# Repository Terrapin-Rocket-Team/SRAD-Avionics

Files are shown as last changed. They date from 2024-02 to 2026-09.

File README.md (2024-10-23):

# SRAD_Avionics
Code and PCBs for the avionics subteam for the SRAD flight computer and side projects.

The avionics subteam manages this repo, as well as the `Multi-Mission-Flight-Software` and `Ground Station`
repositories. Look at the *Issues* tab for tasks that need to be done, and the *Projects* tab for the current
status of the Avionics subteam as a whole. 

Most of our development for our competition rocket systems will be within the `/Spaceport/` directory. Here, the parts 
are broken up by whether they are hardware, PCBs, or code. 

If writing software for the main embedded system, open the [`Teensy-Based-Avionics`](./Spaceport/Code/Teensy-Based-Avionics) 
folder using [Platformio](https://platformio.org/) in VSCode, and make your edits there. For hardware, the files for a single 
board come in sets of 3, with the extensions `.kicad_pro`, `.kicad_pcb`, and `.kicad_sch`. Editing these files affects the 
PCB's layup.

## Setup
Visit the Software Training and Electronics Training modules for more information on how to start learning 
and getting started.

For installation, the `Ground Station` repository is submoduled on this repository. Submodules are not cloned by git by default. 

To clone the submodule when cloning the repo run:
```
git clone --recurse-submodules [url]
```
To clone the submodule within an existing clone of the repo run:
```
git submodule init
git submodule update
```

To get the latest changes for the submodule run:
```
git pull
git submodule update
```

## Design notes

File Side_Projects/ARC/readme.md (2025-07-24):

# Avionics Rotating Camera (ARC)

A live video system able to transmit medium quality 1280x720 30fps video based around the Raspberry Pi 5. It uses AV1 encoding for live video transmission. If you have any questions or would like to contribute, please contact Joseph Hauerstein on Slack or at jhauerst@terpmail.umd.edu.

***This project is still in the early stages of development, so the information here could be imcomplete or inaccurate***

## Setup

Clone the git repository or copy this folder onto a Raspberry Pi, then navigate to this directory in a command window and run the setup script.

```bash 
chmod +x setup.sh && sudo ./setup.sh
```

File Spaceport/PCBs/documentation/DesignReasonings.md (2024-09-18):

## Intro

### All files are located on the `new-pcbs` branch under `Spaceport\24-25\PCBs`.

After the meeting in early July, I wanted to play around designing PCBs because I thought it would be pretty neat. Before this exercise, I knew absolutely nothing about the subject. Everything I learned, I learned from Phil's lab.

[Video #65 specifically](https://www.youtube.com/watch?v=aVUqaB0IMh4).

This 2 part video set was also helpful. [Part 1](https://www.youtube.com/watch?v=nkHFoxe0mrU) & [Part 2](https://www.youtube.com/watch?v=PlXd3lLZ4vc).

**I am hoping to show some proof-of-concept designs to indicate a direction I think we should go as we move towards STM32. Besides the fact that I know nothing about PCB design, there are a few times when I intentionally left a part unfinished or chose a part at random because I just wanted to get the idea across. I am definitely looking for feedback, and the subteam as a whole should have a conversation about desired features and part selection.**

Going into this, I wanted to do multiple PCB parts instead of one large board because I figured that would make fitting everything together in the FC easier. Smaller individual components can more effectively stack to use 3D space than one large plane. My original goal was to have 4 boards:

1. Main board
2. Power board
3. Sensor board
4. Radio board

I figured that keeping the radio and sensors separate would help with RFI. The power board was intended to be a central source for power for the entire Airbrake assembly, rather than the four separate battery types that would be used if we do the same thing as last year. Before I started though, Airbrake noted that they were going to manage their own power again this year, so I scrapped the power board idea and focused on the other three.

## Sensor Board

I started with this board, as Varun had asked me to pick out new sensors to replace the BMP and BNO. After only some preliminary research, I decided to prototype with the MS561101BA03-50 Barometer ([Datasheet](https://www.te.com/commerce/DocumentDelivery/DDEController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) & [DigiKey](https://www.digikey.com/en/products/detail/te-connectivity-measurement-specialties/MS561101BA03-50/5277445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)). It allegedly has better EMI protection than the BMP390, although it is more expensive. For the IMU, I chose the LSM9DS1 9-DOF IMU ([Datasheet](https://www.digikey.de/htmldatasheets/production/1639232/0/0/1/lsm9ds1-datasheet.html) & [DigiKey](https://www.digikey.com/en/products/detail/stmicroelectronics/LSM9DS1TR/4988083)).

The MCU on the sensor board is the STM32F103C8T6 ([Datasheet](https://www.st.com/resource/en/datasheet/stm32f103c8.pdf)). I chose this because Varun said that we had already ordered this and another more powerful version of the STM32. I figured that I would use the more powerful one on the main board and the less powerful one on the sensor board. It is intended to communicate with the main board over I2C.

Here is an image of the schematic for the sensor board, although I recommend looking at the actual file in the repository for a better view.

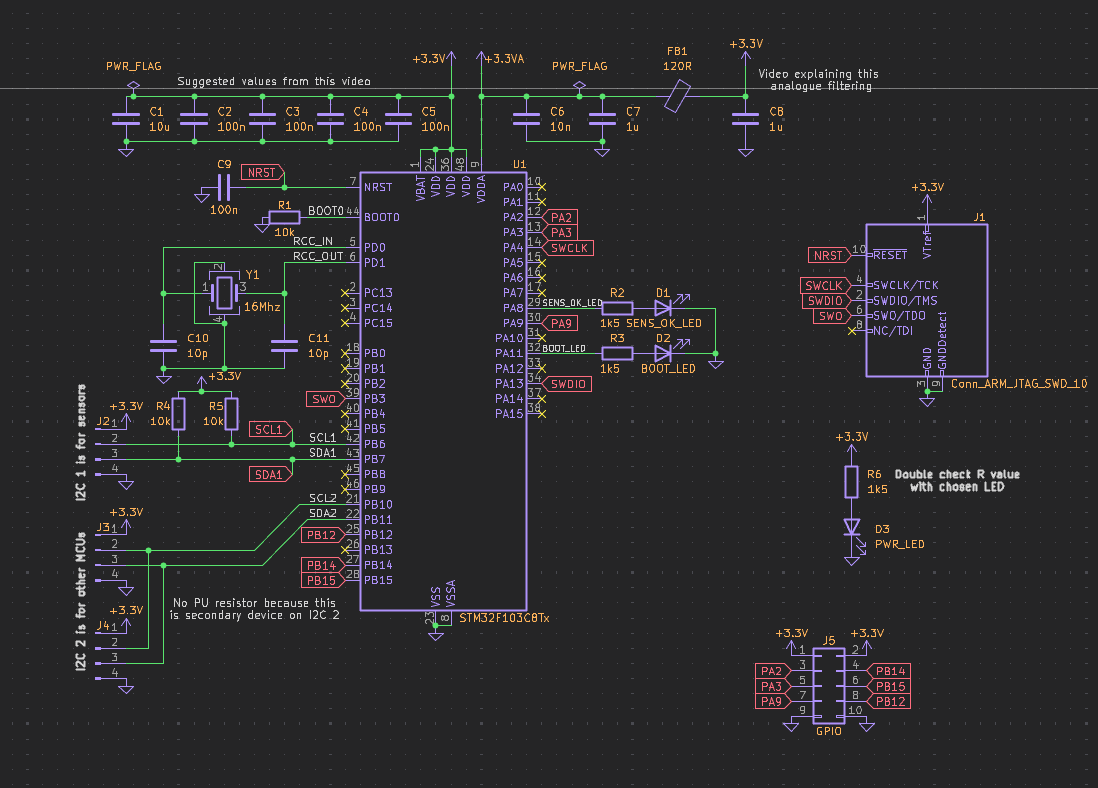
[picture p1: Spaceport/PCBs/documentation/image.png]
MCU Schematic for the sensor board


As this is the first PCB I have ever designed, I am sure that there are many mistakes. I would appreciate any feedback on how to improve this design. Of course, if you have any questions, I can answer those too.

Here is the PCB itself:
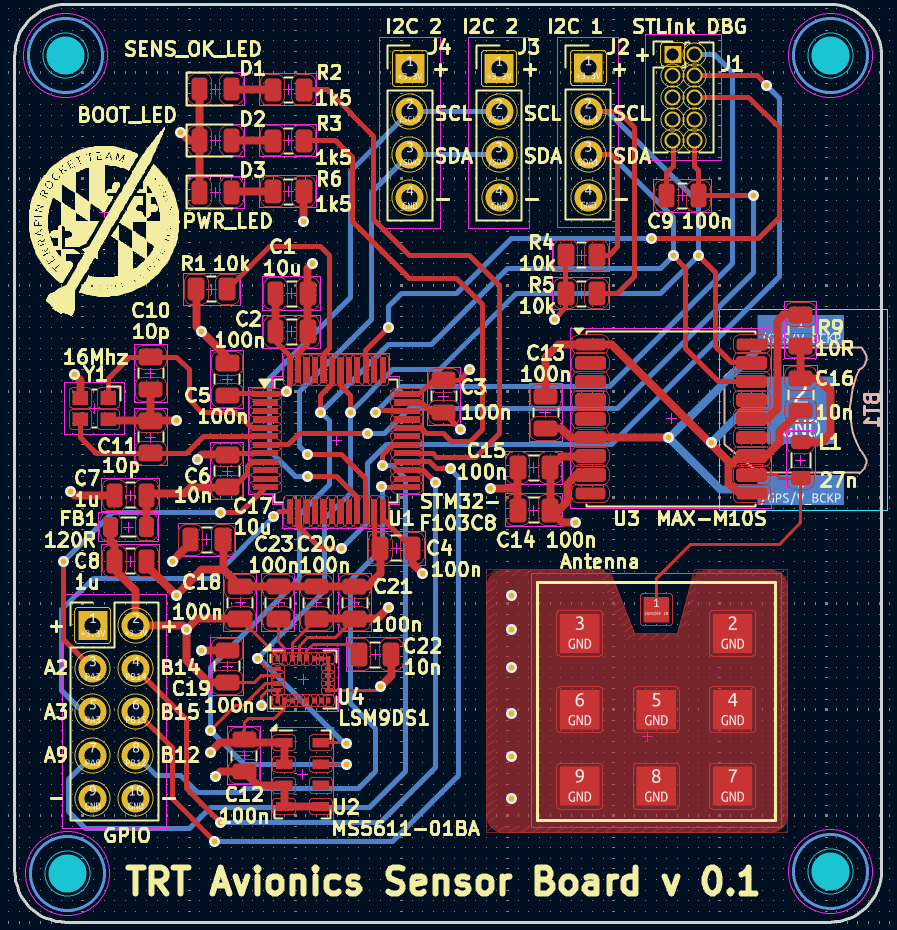
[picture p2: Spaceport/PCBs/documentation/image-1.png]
PCB overview

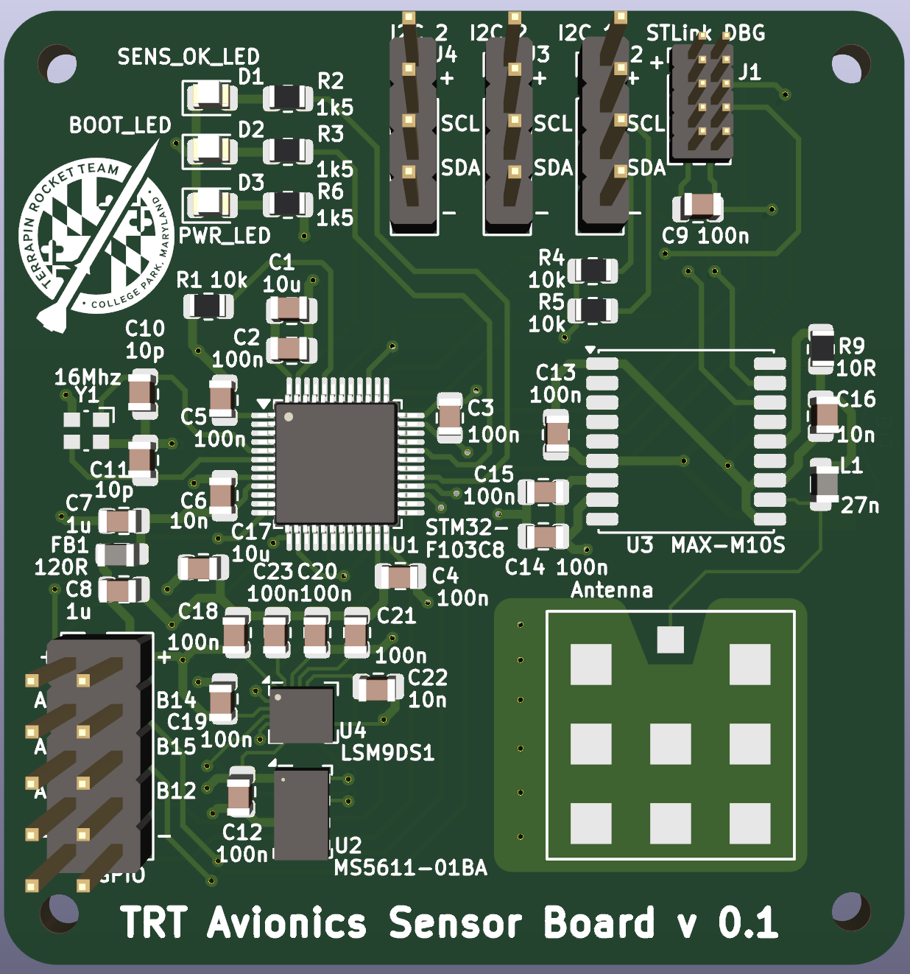
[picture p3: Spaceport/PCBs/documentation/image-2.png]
3D view


Again, please look at the real files and give me any feedback you have. I am sure that there are many mistakes in this design (and errors I didn't feel like fixing, like the size difference of the STLink header).

## Main Board

This is the second PCB I designed. The idea was to create a centralized hub that all peripheral boards would communicate with over I2C. Originally, I was going to implement a custom STLink debugger on this board, similar to how the STM Nucleo boards do. That would make it plug-and play like the teensy where we could upload and debug straight from a single USB port. During design, however, I ran into multiple issues with power management, as we also wanted built-in battery charging and the STLink part would only negotiate for 300mA from the USB host. I decided to scrap the STLink part and focus on the power management and I2C communication.

I'll start with the PCB first this time, as I think it better showcases the idea behind the board.

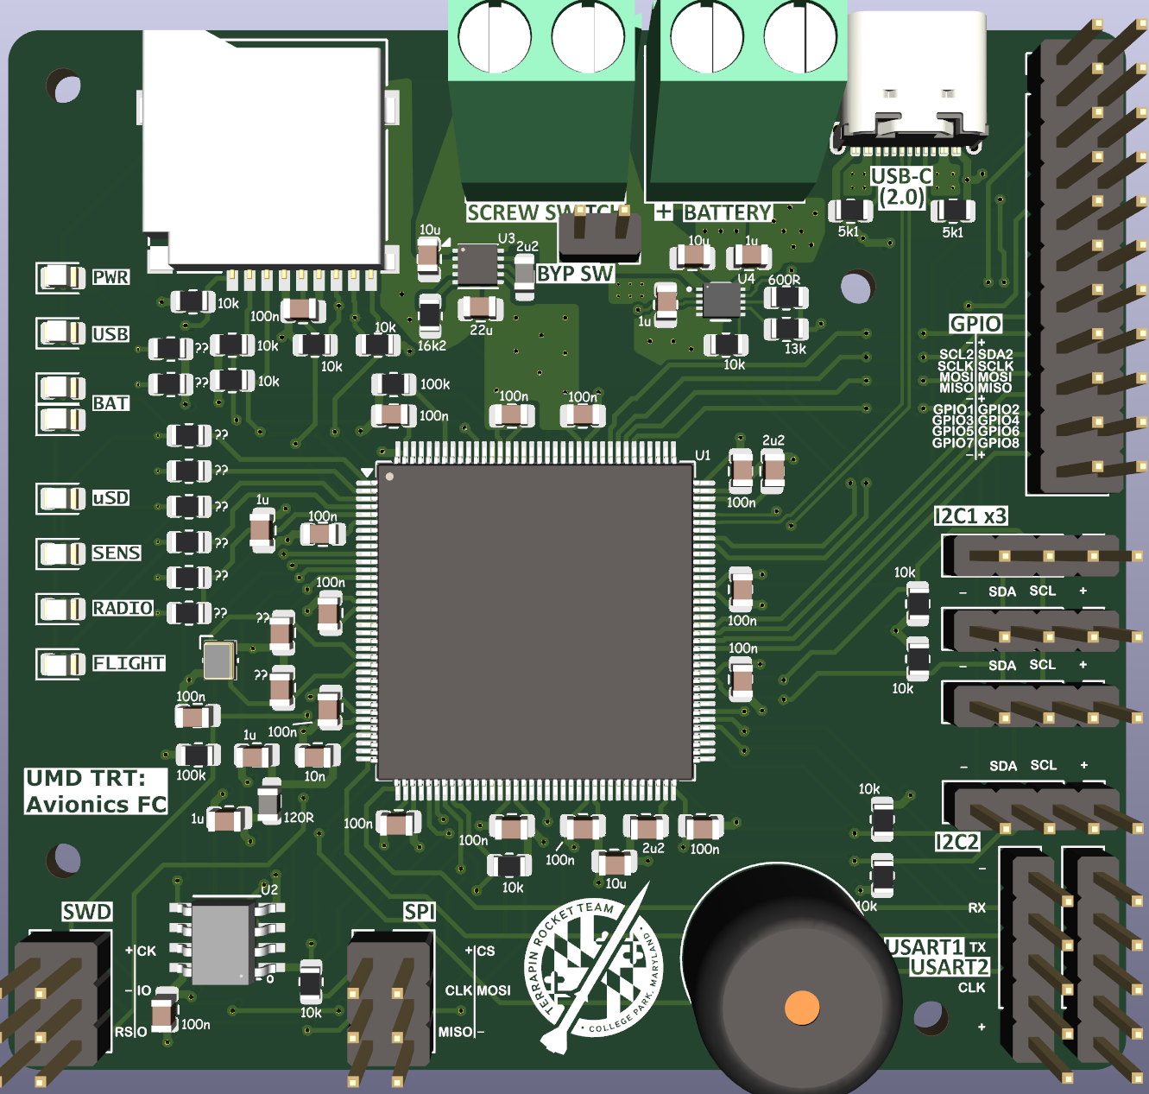
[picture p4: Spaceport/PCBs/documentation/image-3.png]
Main PCB


Unfortunately I forgot about the mounting holes until the end, so you can see they are a bit all over. This board was a bit harder than the other one because it includes battery charging and power switching. I also had to design my own uSD card slot in order to have a complete 3D model set lol.

Once again, much of this is a proof of concept. I wasn't worried about the actual connection types (using pin headers instead of JST or similar, for example). I just wanted to get the idea across.

Here are the other images:
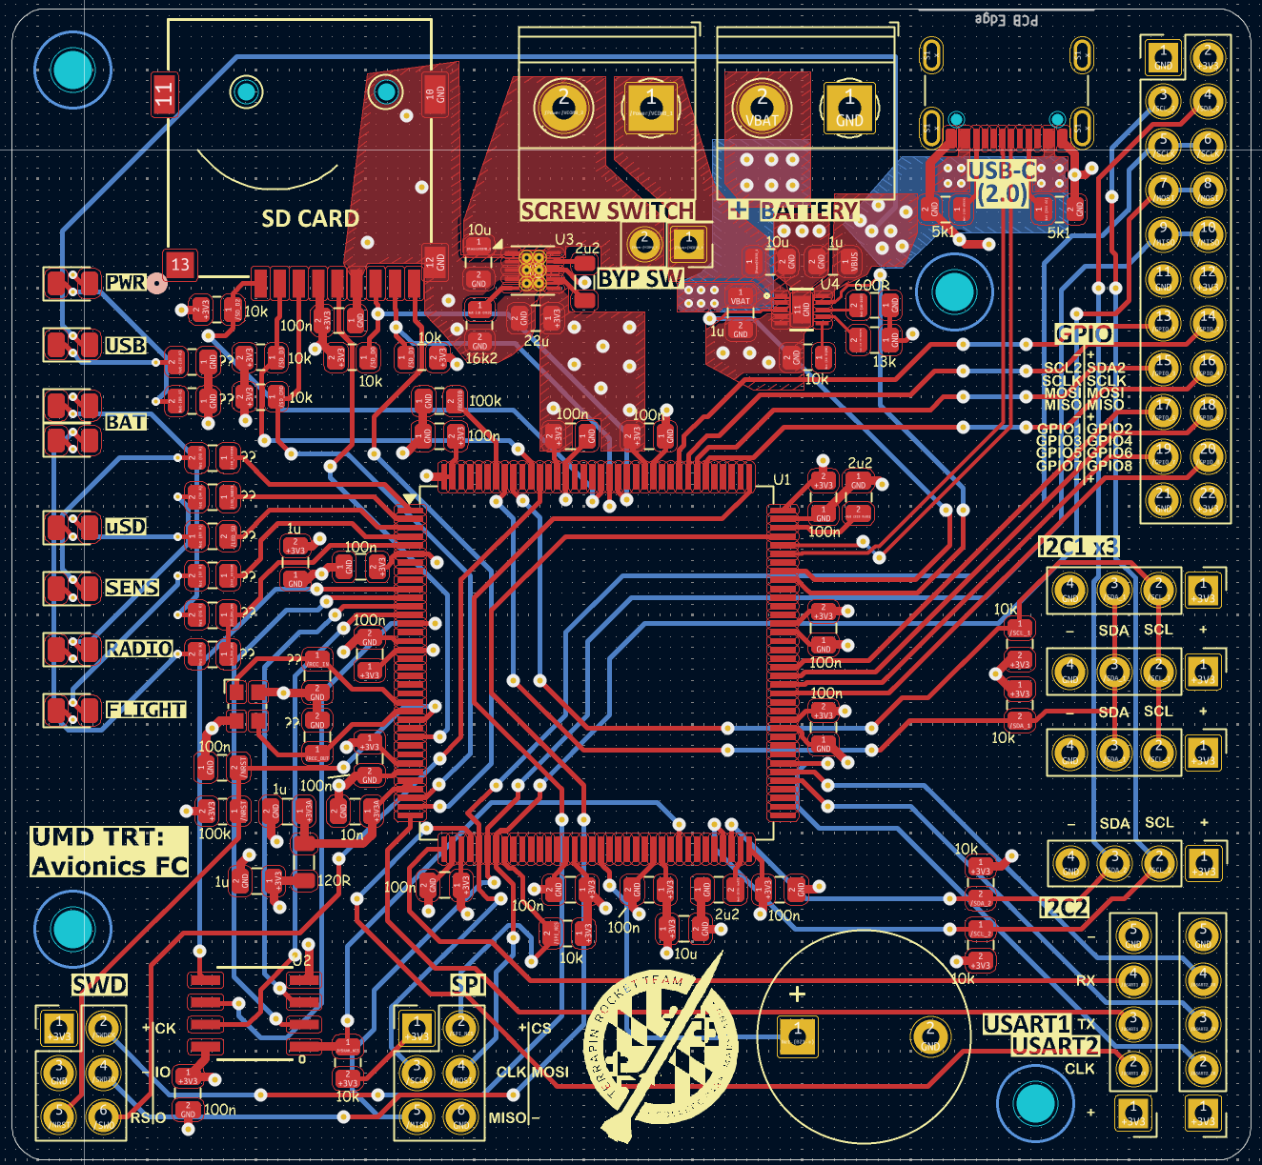
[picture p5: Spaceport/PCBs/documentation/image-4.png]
Main PCB layout

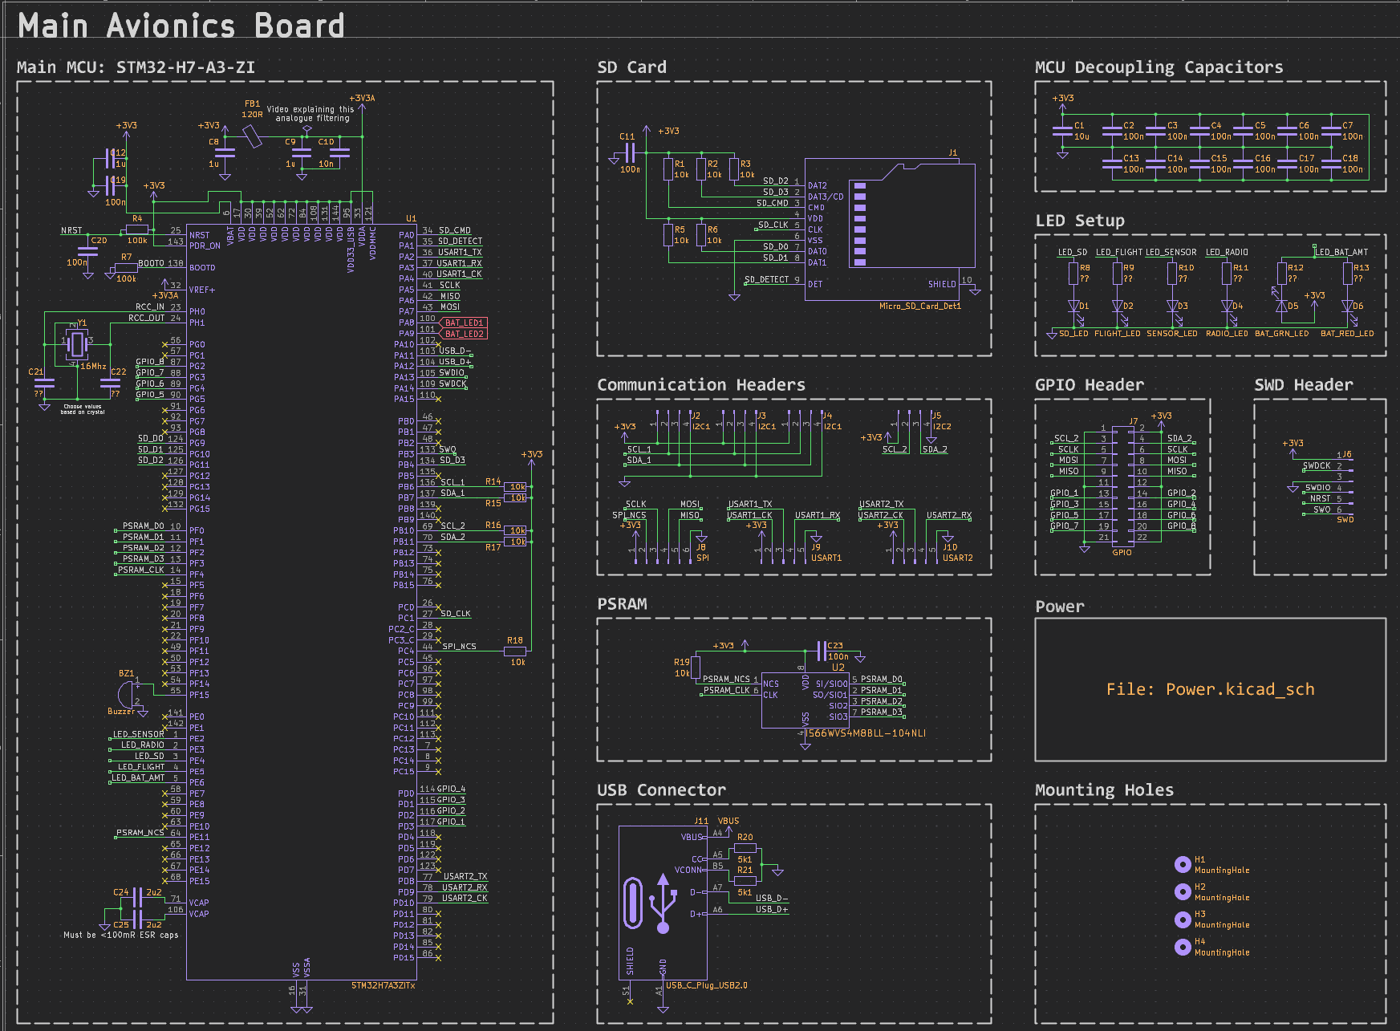
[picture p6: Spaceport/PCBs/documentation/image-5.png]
Main Schematic

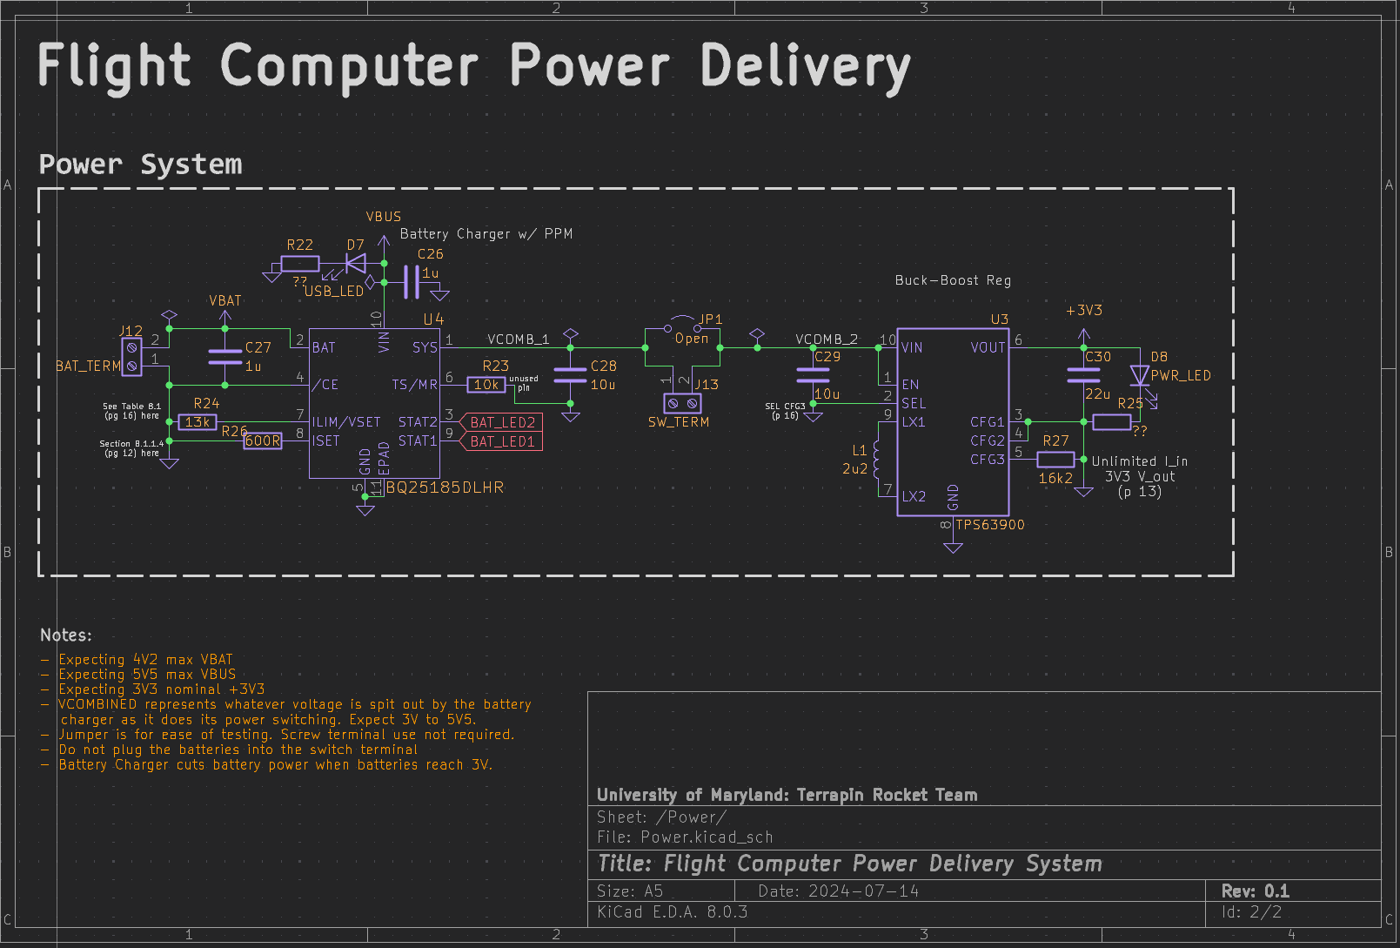
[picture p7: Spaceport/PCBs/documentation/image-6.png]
Main Power Delivery Schematic


As you can see, I left space for a lot of IO pins. Again, this is supposed to be a "hub" kind of board, managing multiple peripherals.

Some notes:

- The BYP SW is a jumper intended to make it easier to test. Just connect/disconnect the jumper to power on/off. When we get to mounting it in the rocket, simply remove the jumper and the screw switch will work instead.
- The `??` resistors are because I had not chosen LEDs, and so didn't know how much current limiting I would need.
- Due to space constraints, I left out the actual identifier in the Silkscreen, opting to only have the value instead.
- I chose USB 2.0 mostly because that's as high as the MCU supports.
- The three I2C1 headers relate to them all being parallel on the I2C1 bus. This is the bus intended to communicate with the other boards. If we need another bus, there are two I2C2 headers (one in the GPIO collection)
- The schematic has links to the datasheets for all the parts I chose

## Wrap-up

I am looking for help reviewing the design and part choices that I made during this process. I have a number of recommendations after doing this exercise:

- We should use JST connectors as they seem to be pretty secure, and we have a lot of them.
- We should decide what kind of LED output we want. I picked some mostly random outputs, but if we have specific things we want to keep track of, we should put an LED there.
- We definitely should discuss parts we want to use. I did some research and picked ones I thought would be reasonable, but they should definitely be double-checked.

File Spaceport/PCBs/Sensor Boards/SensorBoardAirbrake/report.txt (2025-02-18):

Info: Processing symbol 'C1:Capacitor_SMD:C_0603_1608Metric'.
Info: Processing symbol 'R1:Resistor_SMD:R_0805_2012Metric'.
Info: Processing symbol 'C2:Capacitor_SMD:C_0603_1608Metric'.
Info: Processing symbol 'R2:Resistor_SMD:R_0805_2012Metric'.
Info: Processing symbol 'C3:Capacitor_SMD:C_0603_1608Metric'.
Info: Processing symbol 'R3:Resistor_SMD:R_0805_2012Metric'.
Info: Processing symbol 'C4:Capacitor_SMD:C_0603_1608Metric'.
Info: Processing symbol 'R4:Resistor_SMD:R_0805_2012Metric'.
Info: Processing symbol 'C5:Capacitor_SMD:C_0603_1608Metric'.
Info: Processing symbol 'U1:BMI088:PQFN50P450X300X100-16N'.
Info: Processing symbol 'C6:Capacitor_SMD:C_0603_1608Metric'.
Info: Processing symbol 'U2:Package_LGA:LGA-12_2x2mm_P0.5mm'.
Info: Processing symbol 'C7:Capacitor_SMD:C_0805_2012Metric'.
Info: Processing symbol 'C8:Capacitor_SMD:C_0805_2012Metric'.
Info: Processing symbol 'C9:Capacitor_SMD:C_0603_1608Metric'.
Info: Processing symbol 'U3:RF_GPS:ublox_MAX'.
Info: Processing symbol 'C11:Capacitor_SMD:C_0603_1608Metric'.
Info: Processing symbol 'U5:DPS310XTSA1:XDCR_DPS310XTSA1'.
Info: Processing symbol 'C12:Capacitor_SMD:C_0603_1608Metric'.
Info: Processing symbol 'D1:LED_SMD:LED_0805_2012Metric'.
Info: Processing symbol 'H1:MountingHole:MountingHole_3.2mm_M3'.
Info: Processing symbol 'H2:MountingHole:MountingHole_3.2mm_M3'.
Info: Processing symbol 'H3:MountingHole:MountingHole_3.2mm_M3'.
Info: Processing symbol 'H4:MountingHole:MountingHole_3.2mm_M3'.
Info: Processing symbol 'J1:Connector_JST:JST_XH_B4B-XH-A_1x04_P2.50mm_Vertical'.
Info: Processing symbol 'J2:Connector_Coaxial:SMA_Amphenol_901-143_Horizontal'.
Info: Processing symbol 'L1:Inductor_SMD:L_0805_2012Metric'.
Changed C1 footprint from 'Capacitor_SMD:C_0805_2012Metric' to 'Capacitor_SMD:C_0603_1608Metric'.
Changed C2 footprint from 'Capacitor_SMD:C_0805_2012Metric' to 'Capacitor_SMD:C_0603_1608Metric'.
Changed C3 footprint from 'Capacitor_SMD:C_0805_2012Metric' to 'Capacitor_SMD:C_0603_1608Metric'.
Changed C4 footprint from 'Capacitor_SMD:C_0805_2012Metric' to 'Capacitor_SMD:C_0603_1608Metric'.
Changed C5 footprint from 'Capacitor_SMD:C_0805_2012Metric' to 'Capacitor_SMD:C_0603_1608Metric'.
Changed C6 footprint from 'Capacitor_SMD:C_0805_2012Metric' to 'Capacitor_SMD:C_0603_1608Metric'.
Changed C9 footprint from 'Capacitor_SMD:C_0805_2012Metric' to 'Capacitor_SMD:C_0603_1608Metric'.
Changed C11 footprint from 'Capacitor_SMD:C_0805_2012Metric' to 'Capacitor_SMD:C_0603_1608Metric'.
Changed C12 footprint from 'Capacitor_SMD:C_0805_2012Metric' to 'Capacitor_SMD:C_0603_1608Metric'.
Changed U5 value from DPS310 to DPS368.

Info: Total warnings: 0, errors: 0.

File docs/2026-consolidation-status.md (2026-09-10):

# SRAD-Avionics 2026 consolidation status

Last verified: 2026-08-22

This document records repository-reconciliation decisions only. It is not a claim that unfinished hardware or firmware has been completed.

## Consolidated main

- Consolidated `main` commit: `69661d26`
- Previous `main` commit: `90529e94`
- `main` was fast-forwarded on 2026-08-22; no history rewrite was used.

The consolidated history includes the current non-conflicting work from:

- `E22_breakout_board`
- `Jack-Yeulenski-FC2.0`
- `pcb-changes`
- `Macket`
- `STM32-Radio-Module`
- the project files from the sanitized `flight-computer` endpoint

Generated editor state, machine-local settings, a committed Python virtual environment, and redundant PCB backup copies were omitted. Deleted Astra and Astra-Rocket development-branch dependencies were changed to their canonical `main` branches.

## Preserved owner-controlled branches

The following jhauerst-owned lines were deliberately not merged or tagged. Leave them intact for their owner:

- `intra-rocket-video`
- `mid-teensy`
- `mpm-telemetry`
- `ARCH-Mega`

The consolidated `main` was explicitly checked and none of those four branch tips is reachable from it.

## Archived obsolete branch tips

These non-jhauerst branch tips were judged obsolete or superseded and were preserved with annotated tags before branch deletion:

- `267-flight-computer---sensors` -> `archive/branch-267-flight-computer-sensors-2025-10-09`
- `85-self-positioning-antenna-system-optional` -> `archive/branch-85-self-positioning-antenna-2025-09-15`
- `launch-7-12` -> `archive/launch-7-12-2025`
- `launch-jan` -> `archive/launch-jan-2026`
- `new_member_project` -> `archive/new-member-project-2026`
- `sdr_dev` -> `archive/sdr-dev-2025`
- `sdr-code-venv` -> `archive/sdr-code-venv-2025`
- `sdr-code` -> `archive/sdr-code-2025`

Three earlier Personal-fork tips are also retained as `archive/personal-*` tags.

## Build matrix

The repository's GitHub Actions workflow runs `platformio run` in every directory containing `platformio.ini`. The same matrix was run locally against the candidate.

Passing projects:

- `Side_Projects/ARC/RS-FEC`
- `Side_Projects/ESP32FC`
- `Side_Projects/Radio_Code` (all five environments)
- `Side_Projects/STM32FC`
- `Side_Projects/STM32FC-BPP`
- `Side_Projects/STM32FCTest`
- `Side_Projects/TeensyFCTest`
- `Side_Projects/Umbilical`
- `Spaceport/Code/ESP32-Bluetooth`
- `Spaceport/Code/STM32-Motor-Driver`

Known failing or mixed projects, intentionally left for future development:

- `Side_Projects/ARC/live-video-teensy`: current RadioMessage API mismatch.
- `Side_Projects/ESP32GS`: `esp32s3` passes; `ESP32GS` lacks the NimBLE dependency/source separation it needs.
- `Spaceport/Code/ARCH-Mega`: current STM32 `main` environment passes; legacy Teensy and Uno environments do not match the STM32 pin map. Its owner branch remains unmerged.
- `Spaceport/Code/Ground-Receiver`: both environments have source-level message/stream type errors.
- `Spaceport/Code/Kalman-Filter/Matrix-Benchmark`: missing BMP3XX build dependency.
- `Spaceport/Code/Radio`: nine Teensy environments pass; the obsolete Uno environment assumes `Serial1`.
- `Spaceport/Code/Radio-Transceiver`: its legacy Uno/Teensy targets use STM32 pin names, and the STM32L431 custom board lacks a linker script. Newer jhauerst MPM work remains unmerged.
- `Spaceport/Code/STM32FC`: now resolves Astra `main`, but its old sensor adapters use the previous Astra API and reference a removed GPS header.
- `Spaceport/Code/Teensy-Based-Avionics`: the Teensy path references a deliberately removed old Kalman implementation; the experimental STM path lacks a FatFs configuration.

The PlatformIO GitHub Actions workflow uses `find ... -execdir platformio run`.
It can report success even when an individual legacy invocation fails, so its
green status does not supersede the matrix above.

## Clean-room handoff validation

The documented setup was repeated in a new Ubuntu 24.04 WSL2 distribution with
the repositories cloned into the Linux filesystem. No Windows PlatformIO or
compiler installation was placed on the Linux `PATH`.

- Astra-Support `ecfd33a`: installed from GitHub with `pipx`; 30 Python tests passed.
- Astra `4944eda`: four PlatformIO environments built and eight native suites passed (849 cases).
- Astra-Rocket `0695b4c`: five PlatformIO environments built and all 125 native cases passed.
- Consolidated SRAD-Avionics `main`: the Ground Station submodule initialized and `Side_Projects/STM32FC` built successfully against the published Astra and Astra-Rocket commits.
- Astra-Rocket's Windows native build also passed with conditional `ws2_32` linking.

The KiCad DRC GitHub Actions workflow remains failing. The same workflow also
failed on the pre-consolidation `main`; no PCB design changes were made merely
to clear those reports. Hardware upload, HITL, radio, sensor, deployment, and
PCB fabrication checks remain outside this software-only validation.

## Handoff notes

1. Review the PCB conflict choices before fabrication, especially the Teensy MCU project metadata and the sanitized flight-computer import.
2. The existing all-project CI workflow was deliberately left unchanged and can mask the known legacy failures above; consult the recorded matrix.
3. Coordinate separately with jhauerst on his four preserved branch lines.
4. Use `Side_Projects/STM32FC` as the current Astra-Rocket/Astra integration smoke test; hardware behavior is not established by a successful compile.

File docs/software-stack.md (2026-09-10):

# Flight software: install, test, simulate, and integrate

This is the canonical user workflow for the Terrapin Rocket Team flight-software
stack. Start here on a new machine. Each repository remains authoritative for
its own API and hardware details; this page owns the order in which the pieces
are installed and verified together.

The commands below were exercised during the August 2026 handoff pass in a
fresh Ubuntu 24.04 WSL distro. Software-only validation cannot certify attached
sensors, storage, radios, actuators, recovery systems, or flight readiness.

## 1. Understand the stack

```text
Astra-Support  installs tools; diagnoses; builds; tests; runs SITL/HITL
      |
      v
Astra          sensors; state estimation; logging; HITL/SITL primitives
      |
      v
Astra-Rocket   rocket stages; flight defaults; ARC command bridge
      |
      +-------------------------+
      v                         v
SRAD-Avionics                 Airbrake
board/mission integration     controller, motor, telemetry, custom simulation
```

| Repository | Current user entry point |
| --- | --- |
| [Astra-Support](https://github.com/Terrapin-Rocket-Team/Astra-Support) | CLI installation and command reference |
| [Astra](https://github.com/Terrapin-Rocket-Team/Astra) | [Astra user documentation](https://terrapin-rocket-team.github.io/Astra/) |
| [Astra-Rocket](https://github.com/Terrapin-Rocket-Team/Astra-Rocket) | [Astra-Rocket user documentation](https://terrapin-rocket-team.github.io/Astra-Rocket/) |
| [Airbrake](https://github.com/Terrapin-Rocket-Team/Airbrake) | Root README, then `Astra-Rocket/` |
| [SRAD-Avionics](https://github.com/Terrapin-Rocket-Team/SRAD-Avionics) | This page, `Side_Projects/STM32FC`, and the validation checklist |

Use Astra for reusable flight-software behavior, Astra-Rocket for reusable
rocket behavior, and the application repositories for wiring and mission
decisions. Do not fix an application problem by copying an upstream library
into it.

## 2. Prepare a clean development environment

WSL or native Linux is recommended for reproducible command-line work. Keep
repositories in the Linux filesystem (for example `~/trt`), not under
`/mnt/c`, because PlatformIO performs many small file operations.

On Windows, install Ubuntu 24.04 from an elevated PowerShell terminal if it is
not already available:

```powershell
wsl --install -d Ubuntu-24.04
```

Inside Ubuntu:

```bash
sudo apt update
sudo apt install git pipx g++
pipx ensurepath
```

Close and reopen the shell. Install PlatformIO for direct `pio` commands and
install the shared Astra CLI:

```bash
pipx install platformio
pipx install "git+https://github.com/Terrapin-Rocket-Team/Astra-Support.git@main"
pio --version
astra-support --version
```

For an existing Astra-Support installation, refresh it explicitly:

```bash
pipx install --force "git+https://github.com/Terrapin-Rocket-Team/Astra-Support.git@main"
```

Do not use `sudo pip`, install PlatformIO into the system Python, or manually
inject simulation packages. Astra-Support declares its simulation dependencies.

## 3. Clone the current repositories

```bash
mkdir -p ~/trt
cd ~/trt
git clone https://github.com/Terrapin-Rocket-Team/Astra-Support.git
git clone https://github.com/Terrapin-Rocket-Team/Astra.git
git clone https://github.com/Terrapin-Rocket-Team/Astra-Rocket.git
git clone https://github.com/Terrapin-Rocket-Team/Airbrake.git
git clone --recurse-submodules https://github.com/Terrapin-Rocket-Team/SRAD-Avionics.git
```

For an existing Avionics checkout:

```bash
git -C ~/trt/SRAD-Avionics submodule update --init --recursive
```

Before changing anything, record the baseline:

```bash
for repo in Astra-Support Astra Astra-Rocket Airbrake SRAD-Avionics; do
  git -C "$HOME/trt/$repo" status --short --branch
  git -C "$HOME/trt/$repo" rev-parse HEAD
done
```

Expected handoff state is a clean `main` checkout. Stop and preserve unexpected
local modifications before pulling, switching branches, or cleaning builds.

## 4. Verify the libraries and applications

Run diagnostics first. `doctor` checks the selected project, PlatformIO,
compiler, datasets, and custom simulation hooks:

```bash
astra-support doctor --project ~/trt/Astra
astra-support doctor --project ~/trt/Astra-Rocket
astra-support doctor --project ~/trt/Airbrake/Astra-Rocket
```

Then run the managed matrices:

```bash
astra-support test --project ~/trt/Astra --clean --no-progress
astra-support test --project ~/trt/Astra-Rocket --clean --no-progress
astra-support test --project ~/trt/Airbrake/Astra-Rocket --clean --no-progress
```

Four parallel workers are used by default. On a machine with enough memory:

```bash
astra-support test --project ~/trt/Astra --jobs 8 --no-progress
```

`--clean` removes build outputs but does not update dependencies. Use
`--update-deps` only when intentionally evaluating dependency changes. Initial
clean runs compile each test program and are slower; normal repeat runs reuse
the build cache while retaining parallel suites.

Finally compile the maintained Avionics integration target:

```bash
cd ~/trt/SRAD-Avionics/Side_Projects/STM32FC
pio run
```

Do not begin with a repository-wide SRAD-Avionics build. It deliberately keeps
historical projects that are known not to compile. The STM32FC build proves the
current Astra-Rocket -> Astra application chain compiles; it does not prove the
board works.

## 5. Use Astra and Astra-Rocket in an application

Application `platformio.ini` files should depend on Astra-Rocket `main`, which
in turn owns the Astra dependency:

```ini
lib_deps =
  https://github.com/Terrapin-Rocket-Team/Astra-Rocket.git#main
```

During active development, moving `main` references make integration testing
easy. Before a mission freeze, replace them with reviewed tags or full commit
hashes and record the complete version set.

The application config and `AstraRocket` instance must outlive `setup()`:

```cpp
using namespace astra;
using namespace astra_rocket;

AstraRocketConfig config;
AstraRocket rocket(config);

void setup() {
    config.with6DoFIMU(&imu)
          .withBaro(&baro)
          .withGPS(&gps);

    if (rocket.init() < 0) {
        // Enter a hardware-visible safe failure state.
    }
}

void loop() {
    rocket.update();
}
```

Use the Astra documentation for sensors, transforms, state, and logging. Use
the Astra-Rocket documentation for stages, configuration, and ARC behavior.
Use the application repository for actual pin assignments and mission values.

## 6. Run software-in-the-loop (SITL)

SITL executes native flight software and sends simulated sensor packets over a
local TCP connection. It is the first full behavior check after builds/tests.

### Generic Astra SITL

```bash
cd ~/trt/Astra
astra-support sim list --project .
astra-support sim run --project . --mode sitl --source physics --no-plot
```

The native executable is built automatically if missing. Add `--build` after
changing source or `platformio.ini`.

### Airbrake closed-loop SITL

```bash
cd ~/trt/Airbrake/Astra-Rocket
astra-support sim list --project .
astra-support sim run \
  --project . \
  --mode sitl \
  --source airbrake \
  --target-apogee 8382 \
  --no-plot
```

The target apogee is in metres. The Airbrake hook feeds measured flap angle
back into its propagator, allowing motor/controller behavior to affect the
simulated trajectory. A normal run proceeds from pad through landing and writes
`sim_log_*.csv`. Preserve the command, source data, console output, SITL process
log, and CSV when the result is used as test evidence.

`Side_Projects/STM32FC` currently has no native environment or project-specific
simulation hook. Its maintained handoff gate is compilation plus hardware bench
verification. Do not claim Avionics SITL coverage based on the library or
Airbrake runs.

## 7. Run hardware-in-the-loop (HITL)

HITL replaces sensor inputs with simulated packets sent to physical hardware.
It does not make connected actuators or outputs safe.

Before connecting the runner:

1. Record the source revisions and build environment.
2. Disconnect energetic devices and physically safe hazardous outputs.
3. Use approved inert loads and current-limited bench power.
4. Confirm the correct serial port and voltage levels.
5. Ensure the firmware was built specifically for HITL rather than flight.

### Generic Astra HITL

Build an application that calls `withHITL()` and selects the serial interface,
as documented in the [Astra HITL guide](https://terrapin-rocket-team.github.io/Astra/user-guide/hitl/).
After flashing it:

```bash
cd ~/trt/Astra
astra-support sim run \
  --project . \
  --mode hitl \
  --port /dev/ttyACM0 \
  --baud 115200 \
  --source physics \
  --real-time \
  --no-plot
```

### Airbrake HITL

Airbrake supplies a dedicated `teensy41_hitl` environment. It selects Astra's
HITL sensors and must never be used as flight firmware:

```bash
cd ~/trt/Airbrake/Astra-Rocket
pio run -e teensy41_hitl
# Upload with the team's approved Teensy/PlatformIO procedure.

astra-support sim run \
  --project . \
  --mode hitl \
  --port /dev/ttyACM0 \
  --baud 115200 \
  --source airbrake \
  --target-apogee 8382 \
  --real-time \
  --no-plot
```

On Windows, use the correct `COM` port. Airbrake HITL may exercise the physical
motor path; keep the mechanism restrained only according to the approved test
fixture/procedure and maintain an independent means of removing power.

The current SRAD STM32FC application does not select HITL sensors and therefore
must not be connected to this runner with an expectation of Avionics HITL.
Adding a dedicated Avionics HITL environment is future development requiring
hardware-owner review.

## 8. Move from simulation to Avionics bench integration

After software tests and applicable simulation pass:

1. Read the [STM32FC integration reference](stm32fc-integration.md).
2. Copy the [validation checklist](validation-checklist.md) into a dated,
   mission-specific test record.
3. Verify board revision, source pin mappings, sensor identities and axes,
   storage, ARC routing, radio framing, and power behavior independently.
4. Compare local logs, downlinked telemetry, and simulated expectations.
5. Record every anomaly; do not silently tune flight thresholds during a
   release test.

A successful compile, native unit test, SITL run, or HITL run proves only its
own layer. None is a substitute for electrical review, controlled board
bring-up, integrated ground testing, or the team's flight-safety process.

## 9. Freeze and hand off a mission baseline

Before declaring a configuration ready for another team:

- make every relevant working tree clean;
- record all five repository commits and tool versions;
- pin moving dependencies to reviewed revisions;
- archive build output, firmware binaries, maps, hashes, simulation inputs,
  console output, and generated logs;
- complete and review the mission validation checklist;
- tag the accepted source baseline; and
- document unresolved warnings, skipped hardware tests, and responsible owners.

The dated [2026 consolidation status](2026-consolidation-status.md) describes
the repository cleanup baseline and known legacy limitations. Treat it as a
historical handoff record; this page remains the current operational sequence.

## Troubleshooting quick reference

- `astra-support` not found: open a new shell after `pipx ensurepath`.
- `pio` not found: install PlatformIO separately with `pipx install platformio`.
- Unknown environment: run `pio project config` in the directory containing the
  intended `platformio.ini`.
- Stale source/configuration in SITL: add `--build`.
- Dependency changes not appearing: run the relevant matrix once with
  `--update-deps`.
- Serial port busy: close PlatformIO monitor and other terminal programs before
  HITL.
- Airbrake atmosphere import failure: refresh Astra-Support from `main`; do not
  manually edit the installed environment.
- Hardware behavior differs from simulation: stop and treat it as a failed
  integration test, not as permission to adjust values without review.

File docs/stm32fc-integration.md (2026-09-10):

# STM32FC integration reference

This page records what `Side_Projects/STM32FC` currently configures in source.
It is an implementation reference, not evidence that a PCB or assembled flight
computer has passed electrical or flight testing.

## Current target

- MCU/board target: custom STM32H723VEHX PlatformIO board definition
- Framework: STM32 Arduino, C++17
- Application layer: Astra-Rocket from its canonical `main` branch
- ARC node address: nose flight computer (`ARC_ADDR_FC_N`)
- Maintained compile check: `pio run` from `Side_Projects/STM32FC`

The project currently follows moving dependency branches. Pin reviewed release
commits or tags before freezing a mission build.

## Source pin assignments

These assignments come from `src/main.cpp` and `src/LocalFileCommands.cpp`.
Verify every signal against the schematic, PCB revision, assembled board, and
MCU alternate-function mapping before powering hardware or ordering boards.

| Function | Source assignment |
| --- | --- |
| Heartbeat LED | `PE5` |
| Telemetry LED | `PE6` |
| Telemetry UART TX / RX | `PB13` / `PB12` |
| Battery sense ADC | `PC2_C` |
| Radio reset / busy / chip select | `PC13` / `PE3` / `PA15` |
| Radio IO8 / IO9 (IRQ) | `PA3` / `PE2` |
| Radio MOSI / MISO / SCK | `PD7` / `PB4` / `PB3` |
| eMMC D0–D3 | `PC8`, `PC9`, `PC10`, `PC11` |
| eMMC clock / command | `PC12` / `PD2` |

Both diagnostic LEDs are currently treated as active-high. A successful ARC
heartbeat pulses `PE5`; successful telemetry/downlink sends pulse `PE6`. If
`AstraRocket::init()` fails, both LEDs fast-blink together and normal loop
processing never starts.

## Configured sensors and logging

| Role | Current implementation |
| --- | --- |
| IMU | `BMI088` |
| Barometer | `DPS368` |
| GPS | `SAM_M10Q` |
| Magnetometer | `MMC5603NJ` |
| High-G accelerometer | `H3LIS331DL` on `Wire`, address `0x19` |
| Battery monitor | `VoltageSensor`, 422 kΩ / 102 kΩ divider |

The battery telemetry applies a source-level calibration gain of `1.00733` and
offset of `-0.064 V`. Confirm those values against calibrated measurements for
the actual board.

The BMI088 mounting transform is `ROTATE_NEG90_Z` composed with `FLIP_YZ`. The
magnetometer is configured with the identity transform. These are source
assumptions that require an axis/sign test on the installed board.

Data telemetry is written to `data_log.csv` on eMMC. Events are written to
`event_log.csv` on eMMC and also to USB serial. Configured data-log rates are
50 Hz in flight and 10 Hz before and after flight. Astra's file sink may select
a unique suffixed filename when the requested name already exists.

## ARC and downlink path

`TelemetryUART` runs at 115200 baud and is the link to the ARC hub. The current
application sends:

- an ARC network-management heartbeat at 1 Hz;
- ARC flight telemetry addressed to ground at 10 Hz; and
- a vendor data-radio frame, wrapped in ARC `RADIO/DATA_DOWNLINK`, at 1 Hz.

The LR1121-related pins and driver source remain in the project, but `main.cpp`
currently routes the data-radio frame through the ARC hub. It does not use an
onboard radio for that downlink.

`ARC_DEBUG_MIRROR` is currently `1`, which copies raw outgoing ARC frames to USB
serial for diagnostics. The source explicitly says to set it to `0` for flight;
make that an item in the mission configuration review rather than assuming the
development default is flight-ready.

## Local eMMC access

After initialization, the telemetry UART is also registered with Astra's message
router. Newline-terminated local commands use the `FILE/` prefix:

| Command | Effect |
| --- | --- |
| `FILE/LS [path]` | Recursively list a path (root by default) |
| `FILE/CP <path>` | Stream one file between `FILE/BOF` and `FILE/EOF` markers |
| `FILE/RM <path>` | Recursively remove one path |
| `FILE/CLEAR [path]` | Recursively clear a path (root by default) |

`RM` and `CLEAR` are destructive. Recover and verify required logs before using
them, and exercise these commands on non-flight media during bring-up.

## What remains to verify

Compilation does not establish electrical correctness, sensor orientation,
storage integrity, ARC interoperability, stage behavior, or recovery-system
operation. Use the [bench and flight readiness checklist](validation-checklist.md)
and retain its evidence with the mission configuration.

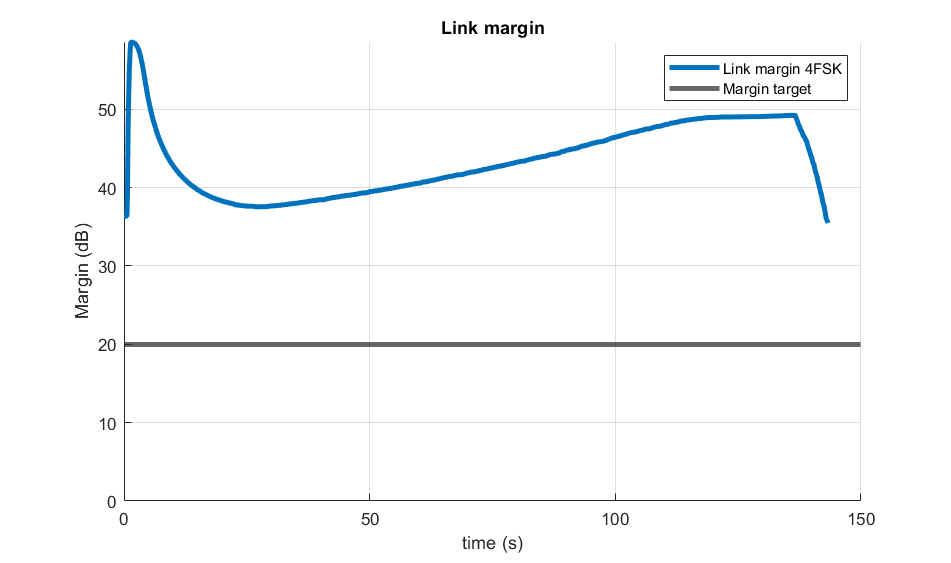
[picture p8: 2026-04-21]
Spaceport/Modeling/Link_Analysis/images/link_margin_report_2026.png

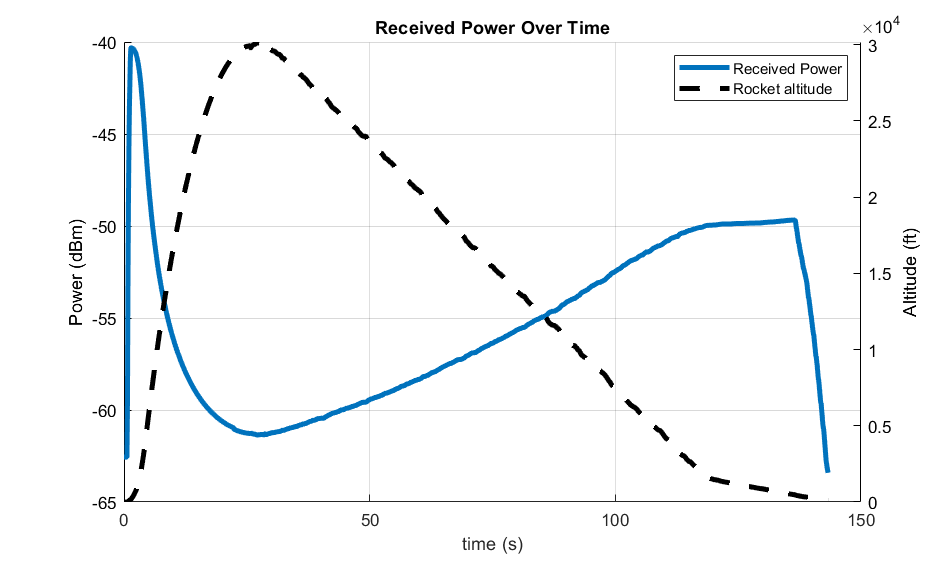
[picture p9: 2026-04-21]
Spaceport/Modeling/Link_Analysis/images/received_power_report_2026.png

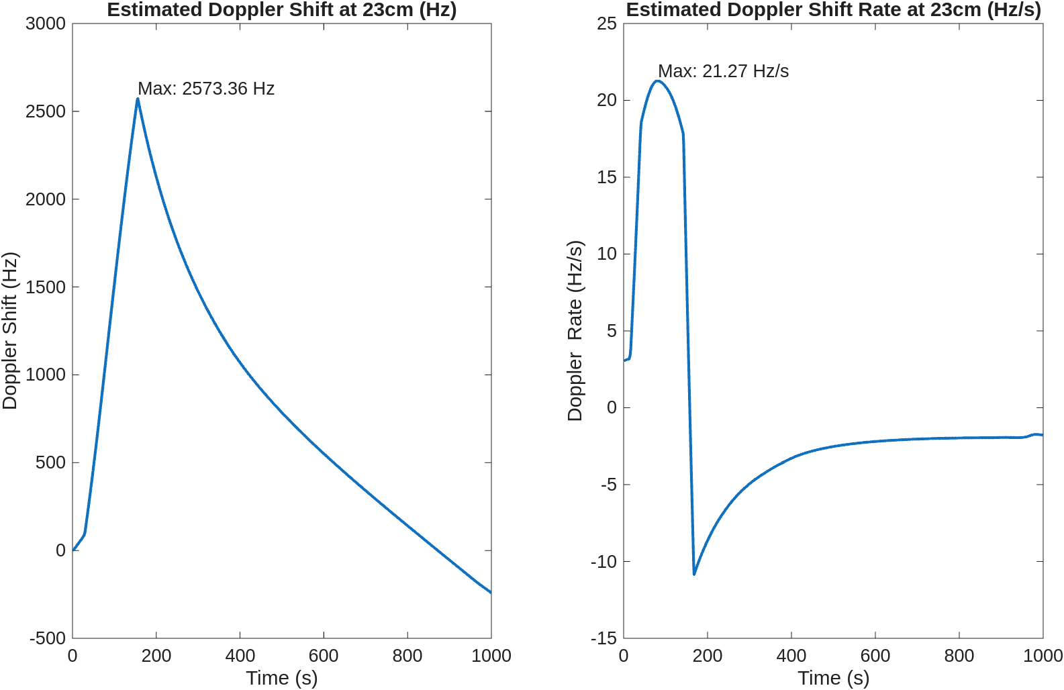
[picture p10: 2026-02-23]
Spaceport/Modeling/DopplerShift/figures/doppler_and_doppler_rate.png

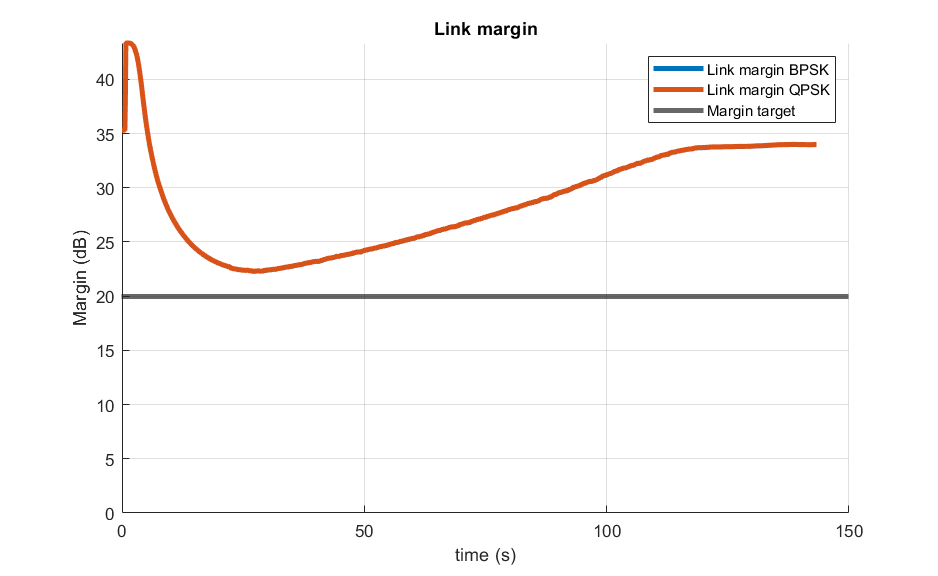
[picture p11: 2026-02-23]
Spaceport/Modeling/Link_Analysis/images/link_margin_PDR2025.png

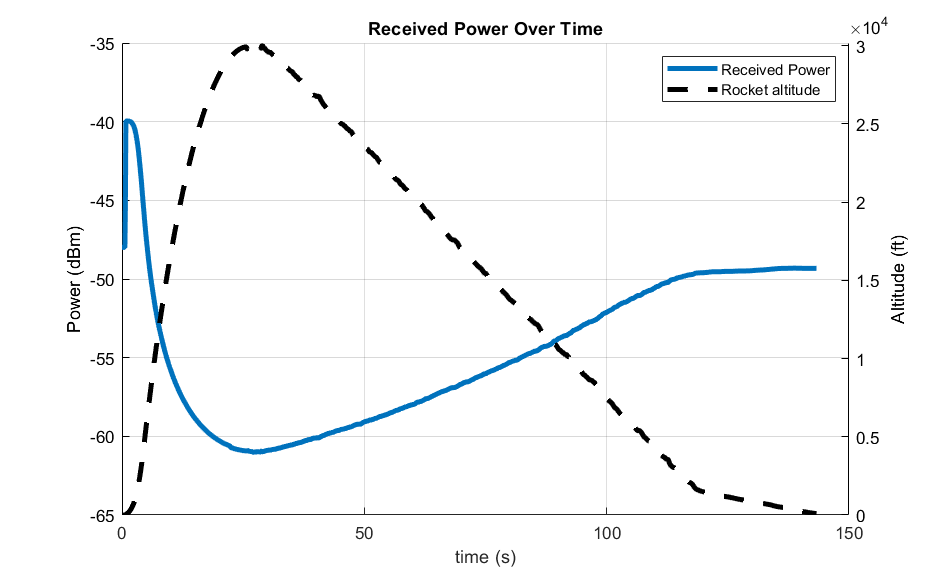
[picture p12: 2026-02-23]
Spaceport/Modeling/Link_Analysis/images/received_power_PDR2025.png

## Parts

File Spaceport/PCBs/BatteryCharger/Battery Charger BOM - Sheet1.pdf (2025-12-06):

Part Number | Description | Size | Status | Price (if applicable) | Link to Part | Datasheet
MCP73831T-3ACI/OT | Battery Charging IC | SOT-23 / 5 | Need to Buy | $0.76 | https://www.digikey.com/en/products/detail/microchip-technology/MCP73831T-3ACI-OT/964307 https://ww1.microchip.com/downloads/en/DeviceDoc/MCP73831-Family-Data-Sheet-DS20001984H.pdf (https://content.u-blox.com/sites/default/files/MAX-M10S_DataSheet_UBX-20035208.pdf)
2 kΩ Resistor | Passive Component | 603 | Available | N/A | N/A | N/A
470 Ω Resistor | Passive Component | 805 | Available | N/A | N/A | N/A
4.7 uF Capacitor | Passive Component | 805 | Need to Buy | N/A | https://www.digikey.com/en/products/detail/nextgen-components/0805B475K250CC/22601895 N/A
4.7 uF Capacitor | Passive Component | 805 | Need to Buy | N/A | https://www.digikey.com/en/products/detail/nextgen-components/0805B475K250CC/22601895 N/A
JST connector | Pin Connections | 2 pin | Need to Buy | 0.1 | https://www.digikey.com/en/products/detail/jst-sales-america-inc/B2B-XH-A/1651045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 https://www.jst-mfg.com/product/pdf/eng/eXH.pdf
JST connector | Pin Connections | 2 pin | Need to Buy | 0.1 | https://www.digikey.com/en/products/detail/jst-sales-america-inc/B2B-XH-A/1651045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 https://www.jst-mfg.com/product/pdf/eng/eXH.pdf
Dupont connector | Pin Connections | 2 pin | Need to Buy | 0.3 | https://www.digikey.com/en/products/detail/sullins-connector-solutions/PRPC002SAAN-RC/2775252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 https://mm.digikey.com/Volume0/opasdata/d220001/medias/docus/386/xRxCzzzSxxN-RC_ST_11635-B.pdf

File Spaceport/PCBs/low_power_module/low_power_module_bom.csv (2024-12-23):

Id | Designator | Footprint | Quantity | Designation | Supplier and ref
1 | CM2,CM3,CM5,CM1 | C_0805_2012Metric_Pad1.18x1.45mm_HandSolder | 4 | 22pF
2 | BZ1 | Adafruit_5V_Buzzer | 1 | Buzzer
3 | RFS1 | CG2409M2 | 1 | CG2409M2
4 | CB2,CB3,CB1 | C_0805_2012Metric_Pad1.18x1.45mm_HandSolder | 3 | 1u
5 | LM1,LM3 | L_0805_2012Metric_Pad1.15x1.40mm_HandSolder | 2 | 10nH
6 | R8,R3,R7,R9,R4,R2,R5,R1,R6 | R_0805_2012Metric_Pad1.20x1.40mm_HandSolder | 9 | 1k
7 | CS1,VCC1,GPIO3,GPIO2,SDN1,GPIO0,STAT1,GPIO1,IRQ1 | LED_0805_2012Metric_Pad1.15x1.40mm_HandSolder | 9 | LED
8 | CM4 | C_0805_2012Metric_Pad1.18x1.45mm_HandSolder | 1 | 15pF
9 | U1 | QFN-20-1EP_4x4mm_P0.5mm_EP2.6x2.6mm_ThermalVias | 1 | Si4463
10 | CD1,CD0,CD2 | C_0805_2012Metric_Pad1.18x1.45mm_HandSolder | 3 | 10uF
11 | J3,J2 | PinHeader_1x03_P2.54mm_Vertical | 2 | Conn_01x03_Pin
12 | CB0 | C_0805_2012Metric_Pad1.18x1.45mm_HandSolder | 1 | 10nF
13 | Teensy4.1 | Teensy_4.1 | 1 | ~
14 | LR2 | L_0805_2012Metric_Pad1.15x1.40mm_HandSolder | 1 | 56nH
15 | LChoke1 | L_0805_2012Metric_Pad1.15x1.40mm_HandSolder | 1 | 220nH
16 | C0 | C_0805_2012Metric_Pad1.18x1.45mm_HandSolder | 1 | 9.1pF
17 | C8,C9 | C_0805_2012Metric_Pad1.18x1.45mm_HandSolder | 2 | 1uF
18 | LR1 | L_0603_1608Metric_Pad1.05x0.95mm_HandSolder | 1 | 62nH
19 | CR2 | C_0805_2012Metric_Pad1.18x1.45mm_HandSolder | 1 | 2.2pF
20 | TCXO2 | TG2520SMN | 1 | TG2520SMN
21 | J1 | SMA_EDGELAUNCH | 1 | SMA
22 | L0 | L_0805_2012Metric_Pad1.15x1.40mm_HandSolder | 1 | 33nH
23 | CR1 | C_0805_2012Metric_Pad1.18x1.45mm_HandSolder | 1 | 4.7pF

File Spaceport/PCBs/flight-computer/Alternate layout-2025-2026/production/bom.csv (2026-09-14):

Designator | Footprint | Quantity | Value | LCSC Part #
BZ1 | Adafruit_5V_Buzzer | 1 | Buzzer
C1, C12, C13, C14, C15, C17, C18, C19, C2, C21, C23, C24, C26, C27, C28, C3, C31, C4, C5, C6 | 0603 | 20 | 100 nF
C10, C11, C32 | 0603 | 3 | 2.2 µF
C16, C35, C40 | 0603 | 3 | 4.7 µF
C20 | CP_Radial_D5.0mm_P2.00mm | 1 | 220 µF
C22 | 1210 | 1 | 100 nF
C25 | 0603 | 1 | 27 pF
C29 | 0603 | 1 | 620 pF
C30, C41, C42, C43, C44 | 1210 | 5 | 10 µF
C33, C36, C8 | 0603 | 3 | 10 µF
C34 | 0603 | 1 | 47 nF
C37 | 1206 | 1 | 20 µF
C39, C9 | 0603 | 2 | 22 µF
C7 | 0603 | 1 | 1 µF
D1, D3, D4, D5, D6, D7 | 0805 | 6 | LED
D2 | SOT-23-3 | 1 | ESDA5V3L
D8, D9 | 0805 | 2 | D_Schottky
IC1, IC2 | Diodes_SO-8EP | 2 | AP7362-33SP-13
J1 | PinHeader_1x05_P2.54mm_Vertical | 1 | SWD
J10 | JST_XH_B2B-XH-A_1x02_P2.50mm_Vertical | 1 | 5.0VOUT
J12 | JST_XH_B2B-XH-A_1x02_P2.50mm_Vertical | 1 | Charge
J13 | PinHeader_1x02_P2.54mm_Vertical | 1 | Conn_01x02
J14 | microSD_HC_Wuerth_693072010801 | 1 | Micro_SD_Card
J2, J3 | JST_XH_B2B-XH-A_1x02_P2.50mm_Vertical | 2 | Conn_01x02
J4 | USB_C_Receptacle_GCT_USB4105-xx-A_16P_TopMnt_Horizontal | 1 | USB_C_Receptacle_USB2.0_16P
J5 | JST_XH_B4B-XH-A_1x04_P2.50mm_Vertical | 1 | UART
J6 | JST_XH_B6B-XH-A_1x06_P2.50mm_Vertical | 1 | UART
J7 | JST_XH_B4B-XH-A_1x04_P2.50mm_Vertical | 1 | I2C
J8 | JST_XH_B6B-XH-A_1x06_P2.50mm_Vertical | 1 | SPI
J9 | JST_XH_B2B-XH-A_1x02_P2.50mm_Vertical | 1 | 3.3VOUT
L1, L4 | L_Sumida_CDMC6D28_7.25x6.5mm | 2 | 2.2uH
L2 | L_TDK_VLS6045EX_VLS6045AF | 1 | 1 uH
L3 | L_TDK_VLS6045EX_VLS6045AF | 1 | 1uH
PS1 | Texas_VQFN-HR-20_3x2.5mm_P0.5mm_RQQ0011A | 1 | TPS61288LRQQR
R1, R19, R2, R23 | 0603 | 4 | 10 kΩ
R10, R11, R18, R5 | 0603 | 4 | 5.1 kΩ
R12 | 0603 | 1 | 15k
R13 | 0603 | 1 | 111k
R14 | 0603 | 1 | 28.7k
R15, R20 | 0603 | 2 | 2 kΩ
R16 | 0603 | 1 | 500k
R17 | 0603 | 1 | 100k
R21, R22 | 0603 | 2 | 100 kΩ
R24 | 0603 | 1 | 78.7 kΩ
R26 | 0603 | 1 | 47 kΩ
R27 | 0603 | 1 | 60K
R3 | 0603 | 1 | 225 Ω
R4 | 0603 | 1 | 160 Ω
R6, R7, R8, R9 | 0603 | 4 | 110 Ω
U1 | LGA-8_3x5mm_P1.25mm | 1 | MS5611-01BA
U10 | QFN-16-1EP_3x3mm_P0.5mm_EP1.75x1.75mm | 1 | MLX90393ELW-ABA-xxx-xx
U2 | Bosch_LGA-16_4.5x3mm_P0.5mm_LayoutBorder7x1y_ClockwisePinNumbering | 1 | BMI088
U3 | QFN300X300X100-16N | 1 | H3LIS331DL
U5 | XCVR_SAM-M10Q-00B | 1 | SAM-M10Q-00B
U6 | SOT-563 | 1 | TPS62A03DRLR
U7 | TFBGA-100_8x8mm_Layout10x10_P0.8mm | 1 | STM32H723VEHx
U8 | Texas_RGE0024H_VQFN-24-1EP_4x4mm_P0.5mm_EP2.7x2.7mm | 1 | BQ25606RGER
U9 | ESP32-S2-MINI-1 | 1 | ESP32-S3-MINI-1-N4R2
Y1 | Oscillator_SMD_ECS_2520MV-xxx-xx-4Pin_2.5x2.0mm | 1 | ECS-2520S

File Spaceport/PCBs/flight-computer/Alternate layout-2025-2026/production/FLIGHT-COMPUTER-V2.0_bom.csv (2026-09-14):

Designator | Footprint | Quantity | Value | LCSC Part #
BZ1 | Buzzer_Murata_PKMCS0909E | 1 | Buzzer
C1, C12, C13, C14, C15, C17, C18, C19, C2, C21, C23, C24, C27, C28, C3, C4, C5, C6, C8 | 0603 | 19 | 100 nF
C10, C11 | 0603 | 2 | 2.2 µF
C16 | 0603 | 1 | 4.7 µF
C20 | 0603 | 1 | 3.3 nF
C41, C42, C43, C44, C9 | 0805 | 5 | 10 µF
C7 | 0805 | 1 | 22 µF
D10 | D_SMA | 1 | D_Schottky
D2 | SOT-23-3 | 1 | ESDA5V3L
D3, D4, D5, D6 | 0805 | 4 | LED
D9 | 0805 | 1 | D_Schottky
IC1, IC2 | Diodes_SO-8EP | 2 | AP7362-33SP-13
J1 | PinHeader_1x05_P2.54mm_Vertical | 1 | SWD
J10 | JST_XH_B2B-XH-A_1x02_P2.50mm_Vertical | 1 | BATT
J11 | TerminalBlock_Phoenix_PT-1,5-4-3.5-H_1x04_P3.50mm_Horizontal | 1 | Conn_01x04
J14 | microSD_HC_Wuerth_693072010801 | 1 | Micro_SD_Card
J2, J3, J5 | JST_XH_B4B-XH-A_1x04_P2.50mm_Vertical | 3 | UART
J4 | USB_C_Receptacle_GCT_USB4105-xx-A_16P_TopMnt_Horizontal | 1 | USB_C_Receptacle_USB2.0_16P
J6 | JST_XH_B2B-XH-A_1x02_P2.50mm_Vertical | 1 | SCREW_SW
J7 | JST_XH_B4B-XH-A_1x04_P2.50mm_Vertical | 1 | I2C
J8 | JST_XH_B6B-XH-A_1x06_P2.50mm_Vertical | 1 | SPI
J9 | JST_XH_B2B-XH-A_1x02_P2.50mm_Vertical | 1 | 3.3VOUT
JP1 | SolderJumper-2_P1.3mm_Open_RoundedPad1.0x1.5mm | 1 | BOOT
L1 | L_Sumida_CDMC6D28_7.25x6.5mm | 1 | 2.2 µH
R1, R10, R11, R18, R2, R5 | 0603 | 6 | 5.1 kΩ
R12 | 0603 | 1 | 11 kΩ
R13, R15, R23, R29, R3, R30, R31 | 0603 | 7 | 10 kΩ
R14 | 0603 | 1 | 8.06 kΩ
R16 | 0603 | 1 | 9.09 kΩ
R17, R20 | 0603 | 2 | 3.3 kΩ
R19, R21 | 0603 | 2 | 100 Ω
R22, R27 | 0603 | 2 | 100 kΩ
R24 | 0603 | 1 | 78.7 kΩ
R25, R28 | 0603 | 2 | 27 kΩ
R26 | 0603 | 1 | 47 kΩ
R32 | 0603 | 1 | 33 Ω
R4 | 0603 | 1 | 38.3 kΩ
R6, R7, R8, R9 | 0603 | 4 | 110 Ω
U1 | LGA-8_3x5mm_P1.25mm | 1 | MS5611-01BA
U10 | QFN-16-1EP_3x3mm_P0.5mm_EP1.75x1.75mm | 1 | MLX90393ELW-ABA-xxx-xx
U2 | Bosch_LGA-16_4.5x3mm_P0.5mm_LayoutBorder7x1y_ClockwisePinNumbering | 1 | BMI088
U3 | QFN300X300X100-16N | 1 | H3LIS331DL
U4 | VQFN-16-1EP_3x3mm_P0.5mm_EP1.68x1.68mm_ThermalVias | 1 | TPS62130
U5 | XCVR_SAM-M10Q-00B | 1 | SAM-M10Q-00B
U6 | SOIC-8_3.9x4.9mm_P1.27mm | 1 | LM393
U7 | TFBGA-100_8x8mm_Layout10x10_P0.8mm | 1 | STM32H723VEHx
U8 | Vishay_PowerPAK_1212-8_Dual | 1 | Si7232DN
Y1 | Oscillator_SMD_ECS_2520MV-xxx-xx-4Pin_2.5x2.0mm | 1 | ECS-2520S

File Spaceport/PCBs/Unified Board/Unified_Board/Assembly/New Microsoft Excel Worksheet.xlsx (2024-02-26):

Comment | Designator | Footprint | LCSC Part Number
SGGP.12.4.A.02 | ANT1 |  | C3284518
BMP390 | Alt1 | LGA-10(2x2) | C5124834
100nF | C1,C2,C3,C4,C7,C8 | 0805 | C77456
22pF | C5,C6 | 0805 | C24658
1uF | C9 | 0805 | C111768
4.7uF | C11 | 0805 | C76639
40V Single 0.55V | D1 | SOD-123 | C5338317
Blue LED | D3,D4,D5,D6 | 0805 | C189307
PESD0402-140 | D7 | 0402 | C7473167
4.7kR | R1,R2,R3,R4 | 0805 | C105427
10kR | R5,R6,R7,R8,R11,R12,R13,R15 | 0805 | C100047
3.3kR | R9 | 0805 | C114531

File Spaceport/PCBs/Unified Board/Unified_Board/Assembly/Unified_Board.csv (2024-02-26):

Id | Designator | Footprint | Quantity | Designation | Supplier and ref
1 | J3 | PinHeader_1x04_P2.54mm_Vertical | 1 | I2C Breakout
2 | R15,R11,R12,R13 | R_0805_2012Metric | 4 | 10kΩ
3 | C7,C2,C8,C1 | C_0805_2012Metric | 4 | 100nF
4 | ANT1 | SGGP.12.A | 1 | ~
5 | C12 | C_0805_2012Metric | 1 | LP_C
6 | D5 | LED_0805_2012Metric_Pad1.15x1.40mm_HandSolder | 1 | IMU_LED
7 | C11 | C_0805_2012Metric | 1 | 4.7uF
8 | J1,J7 | TerminalBlock_4Ucon_1x02_P3.50mm_Vertical | 2 | Screw_Terminal_01x02
9 | R4,R3 | R_0805_2012Metric | 2 | 4.7k
10 | R16 | R_0805_2012Metric | 1 | LP_R
11 | Alt1 | BMP390 | 1 | ~
12 | C5,C6 | C_0805_2012Metric | 2 | 22pF
13 | H1,H3,H2,H4 | MountingHole_2.7mm_M2.5 | 4 | MountingHole
14 | D4 | LED_0805_2012Metric_Pad1.15x1.40mm_HandSolder | 1 | BMP_LED
15 | D3 | LED_0805_2012Metric_Pad1.15x1.40mm_HandSolder | 1 | GPS_LED
16 | J2 | PinHeader_1x04_P2.54mm_Vertical | 1 | Serial2 Breakout
17 | U1 | LGA-28_5.2x3.8mm_P0.5mm | 1 | BNO055
18 | R7,R6,R5,R8 | R_0805_2012Metric | 4 | 10K
19 | Y1 | Crystal_SMD_MicroCrystal_CC7V-T1A-2Pin_3.2x1.5mm | 1 | 32.768kHz
20 | U2 | ublox_MAX | 1 | MAX-M10S
21 | J4 | PinHeader_1x04_P2.54mm_Vertical | 1 | Serial1 Breakout
22 | FB1 | L_0805_2012Metric | 1 | LP_FerriteBead
23 | J5 | PinHeader_1x05_P2.54mm_Vertical | 1 | Conn_01x05_Pin
24 | J6 | PinHeader_1x09_P2.54mm_Vertical | 1 | RFM69HCW
25 | D1 | D_SOD-123 | 1 | .5A/40V/420mV
26 | R1,R2 | R_0805_2012Metric_Pad1.20x1.40mm_HandSolder | 2 | 4.7kΩ
27 | D6 | LED_0805_2012Metric_Pad1.15x1.40mm_HandSolder | 1 | LED
28 | R9 | R_0805_2012Metric | 1 | 3.3kΩ
29 | C9 | C_0805_2012Metric | 1 | 1.0uF
30 | C3,C8,C4 | C_0805_2012Metric | 3 | 0.1uF
31 | BZ1 | Adafruit_5V_Buzzer | 1 | Buzzer
32 | Teensy4.1 | Teensy_4.1 | 1 | ~
33 | D7 | D_0402_1005Metric_Pad0.77x0.64mm_HandSolder | 1 | PESD0402
34 | BT1 | BatteryHolder_Keystone_2998_1x6.8mm | 1 | 6.8mm_coin_cell_GPS

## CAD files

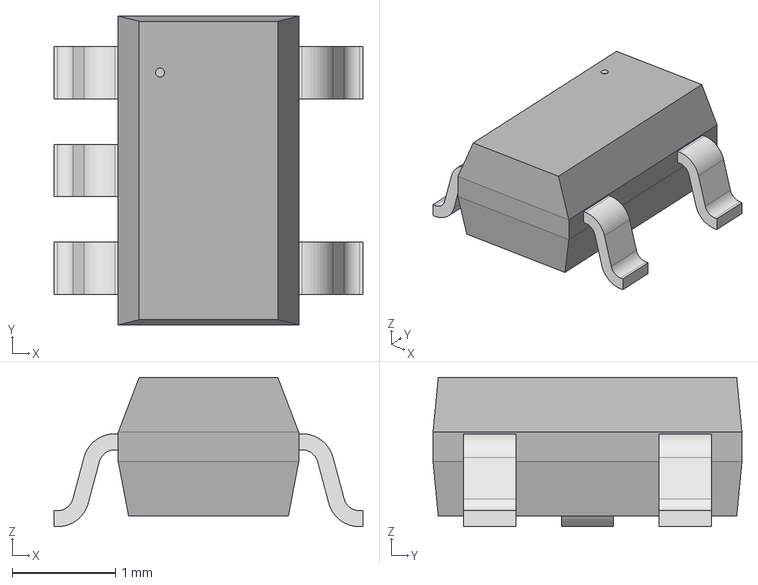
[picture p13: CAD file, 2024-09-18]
Spaceport/PCBs/MCU Boards/STLinkV2-1/LD3985M33R/SOT23-5L_STM.step
3.00 x 3.00 x 1.45 mm

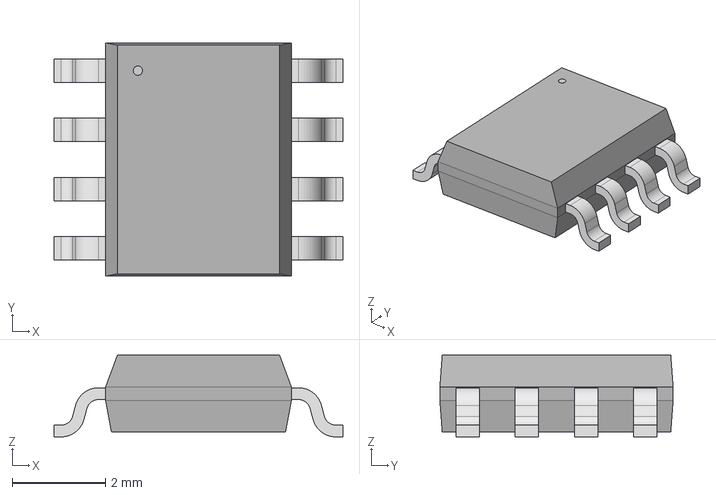
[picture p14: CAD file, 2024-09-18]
Spaceport/PCBs/MCU Boards/STM32 MCU Large/IS66WVS2M8BLL-104NLI/SOIC8_150MIL_N_ISI.step
6.20 x 5.00 x 1.75 mm

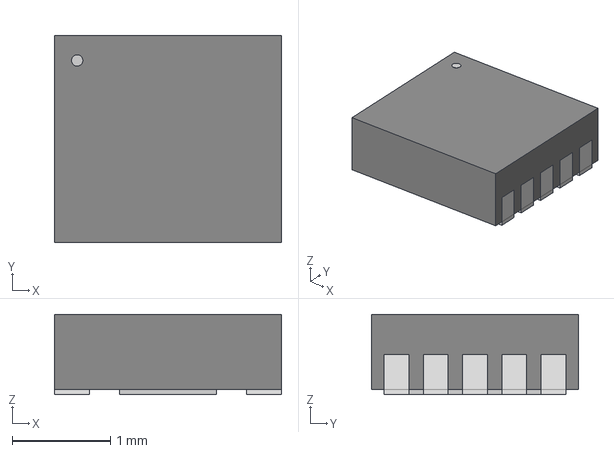
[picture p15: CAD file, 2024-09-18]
Spaceport/PCBs/MCU Boards/STM32 MCU Large/ul_BQ25185DLHR/WSON10_DLH_TEX.step
2.31 x 2.11 x 0.815 mm

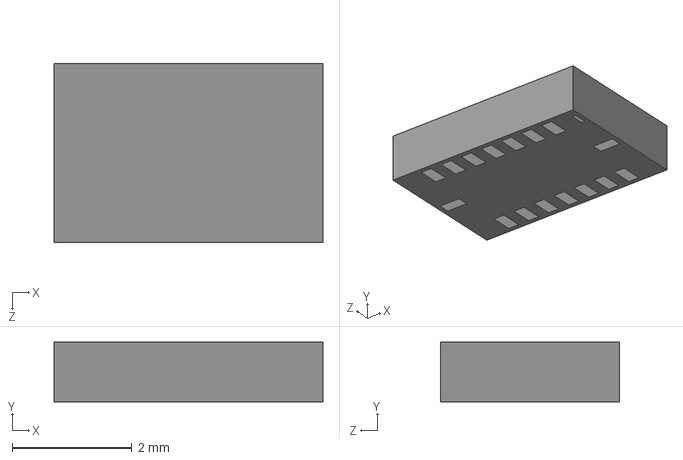
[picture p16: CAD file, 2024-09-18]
Spaceport/PCBs/Sensor Boards/SensorBoardAirbrake/BMI088/BMI088.step
4.50 x 1.00 x 3.00 mm

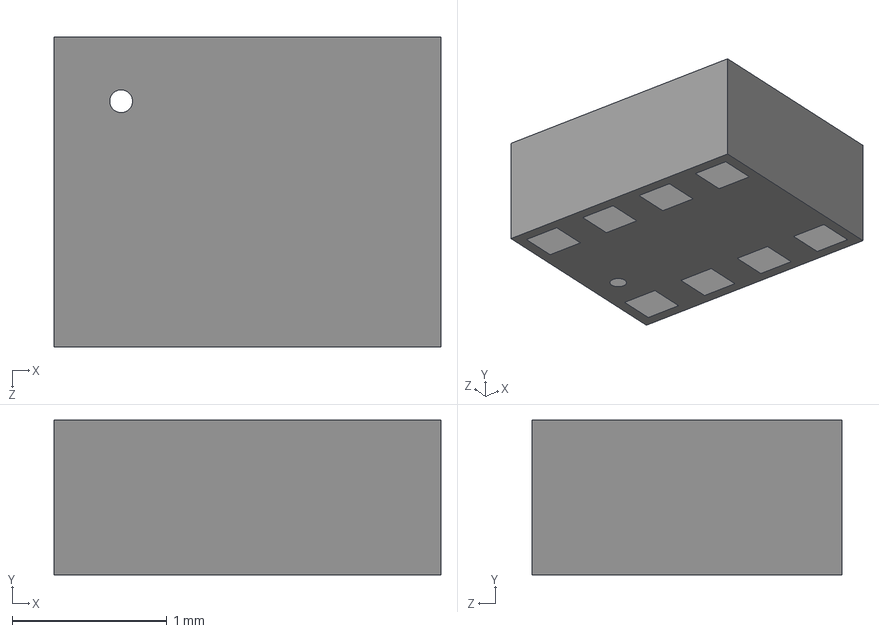
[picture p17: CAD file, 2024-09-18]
Spaceport/PCBs/Sensor Boards/SensorBoardAirbrake/DPS310XTSA1/DPS310XTSA1.step
2.50 x 1.00 x 2.00 mm

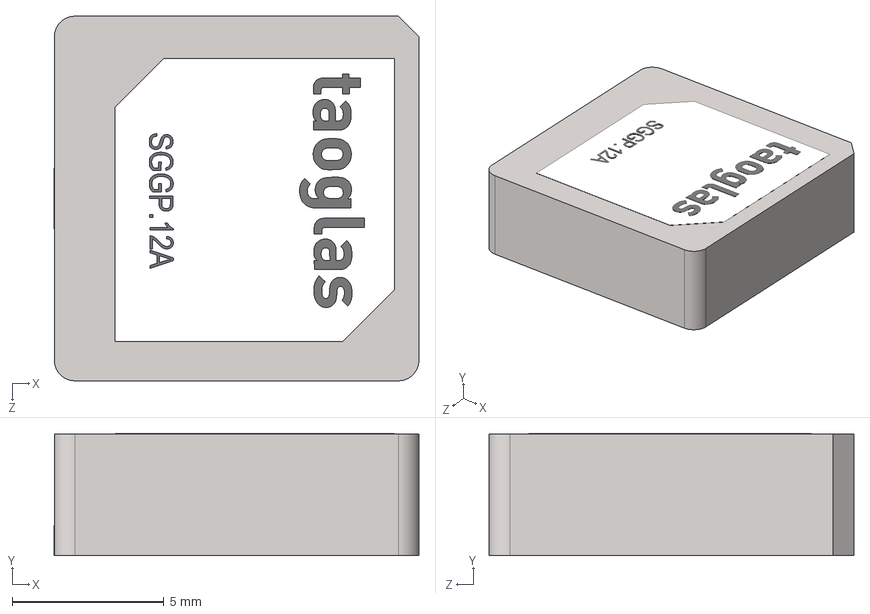
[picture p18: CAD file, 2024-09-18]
Spaceport/PCBs/Sensor Boards/SensorBoardAirbrake/M10s/SGGP.12.4.A.02_Web.STEP
12.0 x 4.03 x 12.0 mm

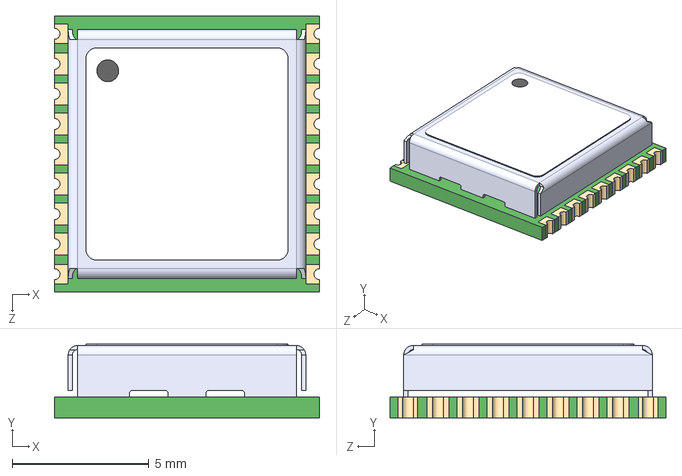
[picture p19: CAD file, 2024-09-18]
Spaceport/PCBs/Sensor Boards/SensorBoardAirbrake/M10s/MAX-M8C-0-10--3DModel-STEP-56544.STEP
9.70 x 2.70 x 10.1 mm

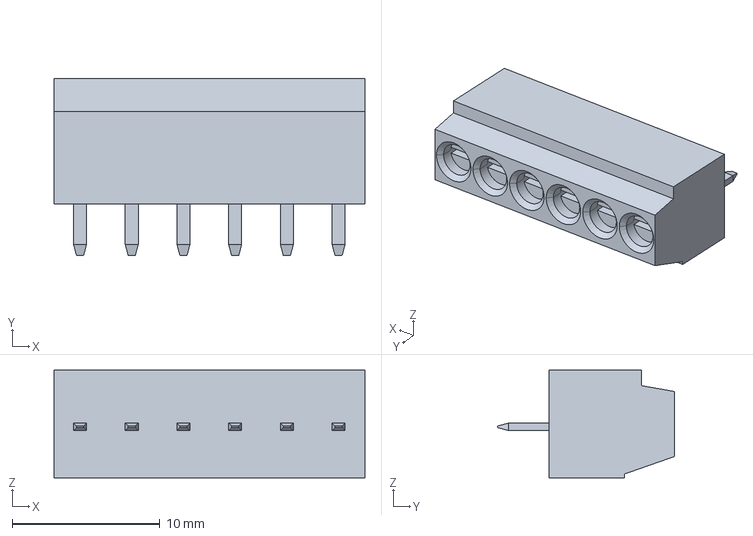
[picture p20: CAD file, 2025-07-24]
Spaceport/PCBs/Blue Raven Extension/393570006.stp
21.1 x 12.0 x 7.29 mm

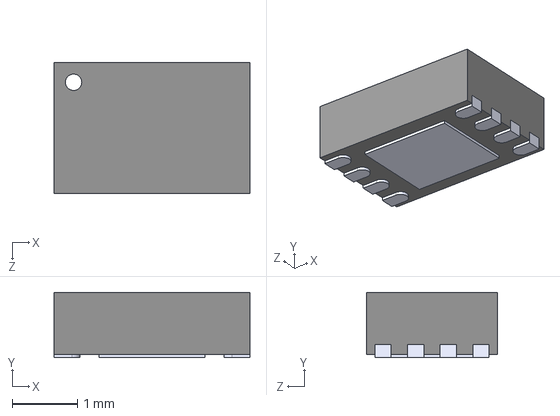
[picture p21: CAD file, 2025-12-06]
Spaceport/PCBs/LiBatteryCharger/Components/MCP73831/MCP73831-2ACI_MC.step
3.00 x 1.00 x 2.00 mm

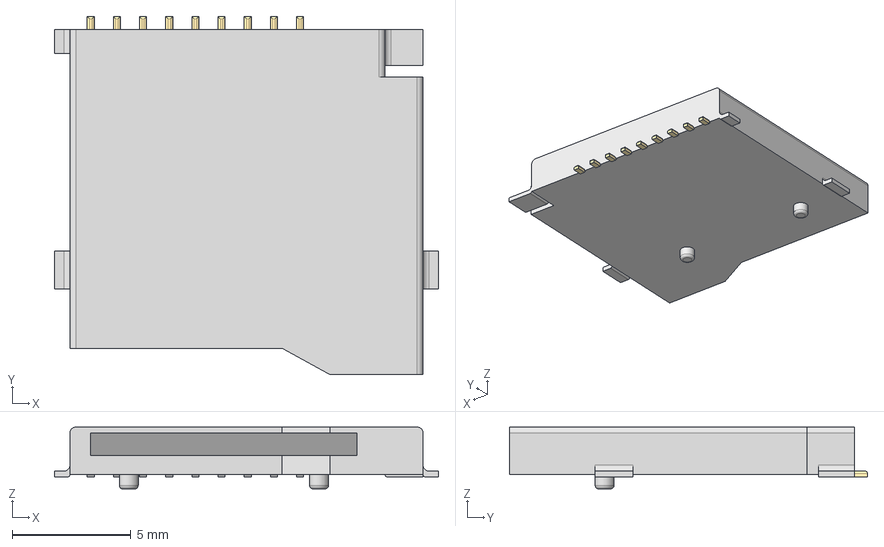
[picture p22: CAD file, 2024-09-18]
Spaceport/PCBs/MCU Boards/STM32 MCU Large/MSD_1_A/CUI MSD-1-A DigiKey/Part Studio 1 - Part 1.step
16.2 x 15.1 x 2.60 mm

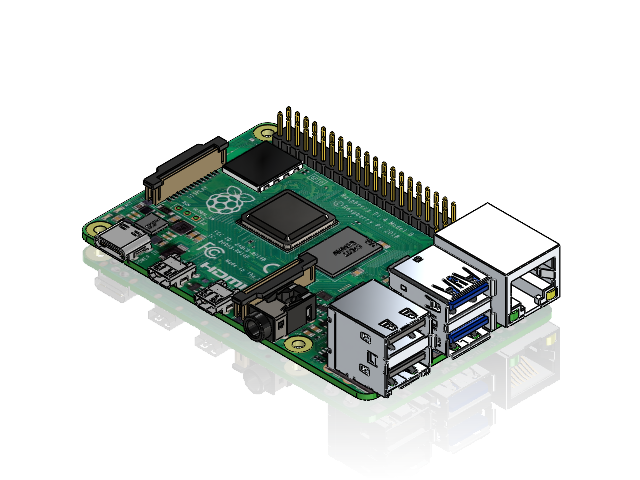
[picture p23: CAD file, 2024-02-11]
Side_Projects/Live Video/CAD/Raspberry Pi 4 Model B.SLDASM
PCB, RPi4ModelB
Broadcom BCM2711B0 CPU, RPi4ModelB
2.54 mm DUPONT MALE PIN HEADER, POE, 2X2, RPi4ModelB
2.54 mm DUPONT MALE PIN HEADER, IO, 2X20, RPi4ModelB
Camera Connector, RPi4ModelB
Microphone Plug, RPi4ModelB
Display Connector, RPi4ModelB
Gigabit Ethernet Port, RPi4ModelB
Female Micro HDMI Connector, RPi4ModelB x 2
Female USB Type C Connector, RPi4ModelB
2X USB3.0 PORTS, RPi4ModelB
91D77 D9WHV 778K, 4 GB LPDDR4 SDRAM, RPi4ModelB
Cypress CYW43455 Wireless Module Cover, RPi4ModelB
SD Card Slot, RPi4ModelB
VIA VL805 PCIe USB 3.0 controller, RPi4ModelB
2X USB2.0 PORTS, RPi4ModelB
Broadcom BCM54213PE Gigabit Ethernet Transceiver, RPi4ModelB
MxL7704 Universal PMIC, RPi4ModelB

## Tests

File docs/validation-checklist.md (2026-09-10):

# STM32FC bench and flight readiness checklist

Copy this checklist into a mission-specific test record. Record the board
revision, operator, date, software commits/tags, toolchain versions, equipment,
observations, and artifact locations for every run. A checked box without saved
evidence is not a completed verification.

## 1. Software baseline

- [ ] Review the mission changes and all transitive dependency revisions.
- [ ] Replace moving branch dependencies with reviewed tags or commit hashes.
- [ ] Record the SRAD-Avionics, Astra-Rocket, Astra, and Astra-Support revisions.
- [ ] Run `astra-support doctor` in each relevant checkout.
- [ ] Run the documented Astra and Astra-Rocket build/test matrices.
- [ ] Run `pio run` in `Side_Projects/STM32FC` from a clean checkout.
- [ ] Archive build output, firmware image, map file, configuration, and hashes.

Stop here if a required build or test fails. Do not repair unrelated behavior as
part of release preparation without review and a separate change record.

## 2. Unpowered board review

- [ ] Match the assembled board revision to the reviewed schematic and PCB.
- [ ] Review component orientation, soldering, connectors, and visible damage.
- [ ] Verify power-rail resistance/continuity and absence of shorts using the
      team's approved electrical procedure.
- [ ] Cross-check the source pin table against the actual board and MCU functions.
- [ ] Confirm that recovery outputs and other hazardous loads are physically
      safed or replaced by approved inert test loads.

## 3. Controlled power and boot

- [ ] Use current-limited bench power and the team's approved bring-up procedure.
- [ ] Confirm expected rails, current draw, reset behavior, and clock/USB startup.
- [ ] Capture the USB event log from boot through `AstraRocket initialized`.
- [ ] Confirm that the dual-fast-blink initialization failure indication is
      detectable and that its logged root cause is actionable.
- [ ] Confirm the heartbeat and telemetry LEDs match their documented events.

## 4. Sensors and state inputs

- [ ] Confirm identity and initialization of the BMI088, DPS368, SAM-M10Q,
      MMC5603NJ, H3LIS331DL, and battery monitor.
- [ ] Exercise each physical axis in a known orientation and verify sign, scale,
      units, and the configured mounting transforms.
- [ ] Compare barometric altitude and temperature with a trusted reference.
- [ ] Verify GPS fix, coordinates, altitude, heading, and raw velocity behavior in
      a suitable outdoor test.
- [ ] Compare battery telemetry across the operating range with calibrated
      measurements; review divider and correction values.
- [ ] Save raw logs and acceptance limits, including failed or marginal runs.

## 5. Storage and recovery

- [ ] Confirm eMMC initialization using the source pin assignment.
- [ ] Verify event and data logs are created, nonempty, parseable, and uniquely
      named across repeated boots.
- [ ] Verify expected 10/50/10 Hz logging behavior with timestamps.
- [ ] Exercise `FILE/LS` and `FILE/CP` and compare recovered files byte-for-byte.
- [ ] Test destructive `FILE/RM` and `FILE/CLEAR` only on disposable test data.
- [ ] Power-cycle during a noncritical write test and document filesystem recovery
      behavior before accepting storage for flight data.

## 6. Communications

- [ ] Verify the 115200-baud UART electrical levels, pin direction, and framing.
- [ ] Confirm the hub learns the `ARC_ADDR_FC_N` route from 1 Hz heartbeats.
- [ ] Decode and validate ARC flight telemetry at 10 Hz against local logs.
- [ ] Verify the wrapped data-radio downlink at 1 Hz through the intended hub and
      radio path; do not infer this from LED activity alone.
- [ ] Test loss, corruption, reconnect, and unavailable-ground scenarios without
      blocking flight-software updates.
- [ ] Review and set `ARC_DEBUG_MIRROR` deliberately for the release build.

## 7. Simulation and mission behavior

- [ ] Run nominal and off-nominal SITL/HITL scenarios with saved inputs and logs.
- [ ] Verify stage transitions, timing, reset behavior, and telemetry mapping.
- [ ] Confirm Astra-Rocket recovery-stage detection is treated as estimation only;
      it is not proof of physical deployment behavior.
- [ ] Review all mission thresholds and configuration values with the responsible
      subsystem owners.

## 8. Recovery and hazardous-output tests

- [ ] Obtain the team's required safety approval and establish a controlled test
      area before connecting any energetic or hazardous hardware.
- [ ] Begin with isolated, current-limited, inert loads and independent measurement.
- [ ] Verify safing, arming interlocks, continuity reporting, channel mapping,
      command inhibition, reset behavior, and fault handling against an approved
      test procedure.
- [ ] Conduct any energetic test only under the organization's authorized safety
      procedure and qualified supervision; this checklist is not that procedure.
- [ ] Require independent review of results before integrated or flight use.

## 9. Integrated ground test and release

- [ ] Repeat representative operation with the assembled avionics stack, power
      system, hub, radios, storage, sensors, and approved inert recovery loads.
- [ ] Verify thermal, vibration, duration, and power conditions defined by the
      mission test plan.
- [ ] Recover and review every local and ground-side log; reconcile timestamps and
      missing packets.
- [ ] Resolve or formally accept every anomaly with an owner and rationale.
- [ ] Tag the accepted source baseline and archive reproducible build instructions.
- [ ] Record final firmware hashes and verify the programmed hardware matches them.
- [ ] Freeze configuration after approval; any later change reopens the affected
      verification stages.

## 10. Post-test or post-flight

- [ ] Preserve original media before deleting, clearing, or transforming logs.
- [ ] Recover and hash eMMC, USB, hub, radio, and ground-station artifacts.
- [ ] Record resets, storage errors, sensor-health changes, dropped links, and stage
      discrepancies.
- [ ] File corrective work separately from the preserved mission baseline.

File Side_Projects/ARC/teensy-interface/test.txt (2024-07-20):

Test1 test2 test3 test4 test5 test6 test7 test8 test9 test10... 
Test1 test2 test3 test4 test5 test6 test7 test8 test9 test10...
Test1 test2 test3 test4 test5 test6 test7 test8 test9 test10...
Test1 test2 test3 test4 test5 test6 test7 test8 test9 test10...
Test1 test2 test3 test4 test5 test6 test7 test8 test9 test10...
Test1 test2 test3 test4 test5 test6 test7 test8 test9 test10...
Test1 test2 test3 test4 test5 test6 test7 test8 test9 test10...
Test1 test2 test3 test4 test5 test6 test7 test8 test9 test10...
Test1 test2 test3 test4 test5 test6 test7 test8 test9 test10...
Test1 test2 test3 test4 test5 test6 test7 test8 test9 test10...
Test1 test2 test3 test4 test5 test6 test7 test8 test9 test10...
Test1 test2 test3 test4 test5 test6 test7 test8 test9 test10...
Test1 test2 test3 test4 test5 test6 test7 test8 test9 test10...
Test1 test2 test3 test4 test5 test6 test7 test8 test9 test10...
Test1 test2 test3 test4 test5 test6 test7 test8 test9 test10...
Test1 test2 test3 test4 test5 test6 test7 test8 test9 test10...
Test1 test2 test3 test4 test5 test6 test7 test8 test9 test10...
Test1 test2 test3 test4 test5 test6 test7 test8 test9 test10...
Test1 test2 test3 test4 test5 test6 test7 test8 test9 test10...
Test1 test2 test3 test4 test5 test6 test7 test8 test9 test10...
Test1 test2 test3 test4 test5 test6 test7 test8 test9 test10...
Test1 test2 test3 test4 test5 test6 test7 test8 test9 test10...
Test1 test2 test3 test4 test5 test6 test7 test8 test9 test10...
Test1 test2 test3 test4 test5 test6 test7 test8 test9 test10...
Test1 test2 test3 test4 test5 test6 test7 test8 test9 test10...
Test1 test2 test3 test4 test5 test6 test7 test8 test9 test10...
Test1 test2 test3 test4 test5 test6 test7 test8 test9 test10...
Test1 test2 test3 test4 test5 test6 test7 test8 test9 test10...
Test1 test2 test3 test4 test5 test6 test7 test8 test9 test10...
Test1 test2 test3 test4 test5 test6 test7 test8 test9 test10...
Test1 test2 test3 test4 test5 test6 test7 test8 test9 test10...
Test1 test2 test3 test4 test5 test6 test7 test8 test9 test10...
Test1 test2 test3 test4 test5 test6 test7 test8 test9 test10...
Test1 test2 test3 test4 test5 test6 test7 test8 test9 test10...
Test1 test2 test3 test4 test5 test6 test7 test8 test9 test10...
Test1 test2 test3 test4 test5 test6 test7 test8 test9 test10...
Test1 test2 test3 test4 test5 test6 test7 test8 test9 test10...
Test1 test2 test3 test4 test5 test6 test7 test8 test9 test10...
Test1 test2 test3 test4 test5 test6 test7 test8 test9 test10...
Test1 test2 test3 test4 test5 test6 test7 test8 test9 test10...
Test1 test2 test3 test4 test5 test6 test7 test8 test9 test10...
Test1 test2 test3 test4 test5 test6 test7 test8 test9 test10...
Test1 test2 test3 test4 test5 test6 test7 test8 test9 test10...
Test1 test2 test3 test4 test5 test6 test7 test8 test9 test10...
Test1 test2 test3 test4 test5 test6 test7 test8 test9 test10...
Test1 test2 test3 test4 test5 test6 test7 test8 test9 test10...
Test1 test2 test3 test4 test5 test6 test7 test8 test9 test10...
Test1 test2 test3 test4 test5 test6 test7 test8 test9 test10...
Test1 test2 test3 test4 test5 test6 test7 test8 test9 test10...
Test1 test2 test3 test4 test5 test6 test7 test8 test9 test10...
Test1 test2 test3 test4 test5 test6 test7 test8 test9 test10...
Test1 test2 test3 test4 test5 test6 test7 test8 test9 test10...
Test1 test2 test3 test4 test5 test6 test7 test8 test9 test10...
Test1 test2 test3 test4 test5 test6 test7 test8 test9 test10...
Test1 test2 test3 test4 test5 test6 test7 test8 test9 test10...
Test1 test2 test3 test4 test5 test6 test7 test8 test9 test10...
Test1 test2 test3 test4 test5 test6 test7 test8 test9 test10...
Test1 test2 test3 test4 test5 test6 test7 test8 test9 test10...
Test1 test2 test3 test4 test5 test6 test7 test8 test9 test10...
Test1 test2 test3 test4 test5 test6 test7 test8 test9 test10...
Test1 test2 test3 test4 test5 test6 test7 test8 test9 test10...
Test1 test2 test3 test4 test5 test6 test7 test8 test9 test10...
Test1 test2 test3 test4 test5 test6 test7 test8 test9 test10...
Test1 test2 test3 test4 test5 test6 test7 test8 test9 test10...
Test1 test2 test3 test4 test5 test6 test7 test8 test9 test10...
Test1 test2 test3 test4 test5 test6 test7 test8 test9 test10...
Test1 test2 test3 test4 test5 test6 test7 test8 test9 test10...
Test1 test2 test3 test4 test5 test6 test7 test8 test9 test10...
Test1 test2 test3 test4 test5 test6 test7 test8 test9 test10...
Test1 test2 test3 test4 test5 test6 test7 test8 test9 test10...
Test1 test2 test3 test4 test5 test6 test7 test8 test9 test10...
Test1 test2 test3 test4 test5 test6 test7 test8 test9 test10...
Test1 test2 test3 test4 test5 test6 test7 test8 test9 test10...
Test1 test2 test3 test4 test5 test6 test7 test8 test9 test10...
Test1 test2 test3 test4 test5 test6 test7 test8 test9 test10...
Test1 test2 test3 test4 test5 test6 test7 test8 test9 test10...
Test1 test2 test3 test4 test5 test6 test7 test8 test9 test10...
Test1 test2 test3 test4 test5 test6 test7 test8 test9 test10...
Test1 test2 test3 test4 test5 test6 test7 test8 test9 test10...
Test1 test2 test3 test4 test5 test6 test7 test8 test9 test10...
Test1 test2 test3 test4 test5 test6 test7 test8 test9 test10...
Test1 test2 test3 test4 test5 test6 test7 test8 test9 test10...
Test1 test2 test3 test4 test5 test6 test7 test8 test9 test10...
Test1 test2 test3 test4 test5 test6 test7 test8 test9 test10...
Test1 test2 test3 test4 test5 test6 test7 test8 test9 test10...
Test1 test2 test3 test4 test5 test6 test7 test8 test9 test10...
Test1 test2 test3 test4 test5 test6 test7 test8 test9 test10...
Test1 test2 test3 test4 test5 test6 test7 test8 test9 test10...
Test1 test2 test3 test4 test5 test6 test7 test8 test9 test10...
Test1 test2 test3 test4 test5 test6 test7 test8 test9 test10...
Test1 test2 test3 test4 test5 test6 test7 test8 test9 test10...
Test1 test2 test3 test4 test5 test6 test7 test8 test9 test10...
Test1 test2 test3 test4 test5 test6 test7 test8 test9 test10...
Test1 test2 test3 test4 test5 test6 test7 test8 test9 test10...
Test1 test2 test3 test4 test5 test6 test7 test8 test9 test10...
Test1 test2 test3 test4 test5 test6 test7 test8 test9 test10...
Test1 test2 test3 test4 test5 test6 test7 test8 test9 test10...
Test1 test2 test3 test4 test5 test6 test7 test8 test9 test10...
Test1 test2 test3 test4 test5 test6 test7 test8 test9 test10...
Test1 test2 test3 test4 test5 test6 test7 test8 test9 test10...
Test1 test2 test3 test4 test5 test6 test7 test8 test9 test10...
Test1 test2 test3 test4 test5 test6 test7 test8 test9 test10...
Test1 test2 test3 test4 test5 test6 test7 test8 test9 test10...
Test1 test2 test3 test4 test5 test6 test7 test8 test9 test10...
Test1 test2 test3 test4 test5 test6 test7 test8 test9 test10...
Test1 test2 test3 test4 test5 test6 test7 test8 test9 test10...
Test1 test2 test3 test4 test5 test6 test7 test8 test9 test10...
Test1 test2 test3 test4 test5 test6 test7 test8 test9 test10...
Test1 test2 test3 test4 test5 test6 test7 test8 test9 test10...
Test1 test2 test3 test4 test5 test6 test7 test8 test9 test10...
Test1 test2 test3 test4 test5 test6 test7 test8 test9 test10...
Test1 test2 test3 test4 test5 test6 test7 test8 test9 test10...
Test1 test2 test3 test4 test5 test6 test7 test8 test9 test10...
Test1 test2 test3 test4 test5 test6 test7 test8 test9 test10...
Test1 test2 test3 test4 test5 test6 test7 test8 test9 test10...
Test1 test2 test3 test4 test5 test6 test7 test8 test9 test10...
Test1 test2 test3 test4 test5 test6 test7 test8 test9 test10...
Test1 test2 test3 test4 test5 test6 test7 test8 test9 test10...
Test1 test2 test3 test4 test5 test6 test7 test8 test9 test10...
Test1 test2 test3 test4 test5 test6 test7 test8 test9 test10...
Test1 test2 test3 test4 test5 test6 test7 test8 test9 test10...
Test1 test2 test3 test4 test5 test6 test7 test8 test9 test10...
Test1 test2 test3 test4 test5 test6 test7 test8 test9 test10...
Test1 test2 test3 test4 test5 test6 test7 test8 test9 test10...
Test1 test2 test3 test4 test5 test6 test7 test8 test9 test10...
Test1 test2 test3 test4 test5 test6 test7 test8 test9 test10...
Test1 test2 test3 test4 test5 test6 test7 test8 test9 test10...
Test1 test2 test3 test4 test5 test6 test7 test8 test9 test10...
Test1 test2 test3 test4 test5 test6 test7 test8 test9 test10...
Test1 test2 test3 test4 test5 test6 test7 test8 test9 test10...
Test1 test2 test3 test4 test5 test6 test7 test8 test9 test10...
Test1 test2 test3 test4 test5 test6 test7 test8 test9 test10...
Test1 test2 test3 test4 test5 test6 test7 test8 test9 test10...
Test1 test2 test3 test4 test5 test6 test7 test8 test9 test10...
Test1 test2 test3 test4 test5 test6 test7 test8 test9 test10...
Test1 test2 test3 test4 test5 test6 test7 test8 test9 test10...
Test1 test2 test3 test4 test5 test6 test7 test8 test9 test10...
Test1 test2 test3 test4 test5 test6 test7 test8 test9 test10...
Test1 test2 test3 test4 test5 test6 test7 test8 test9 test10...
Test1 test2 test3 test4 test5 test6 test7 test8 test9 test10...
Test1 test2 test3 test4 test5 test6 test7 test8 test9 test10...
Test1 test2 test3 test4 test5 test6 test7 test8 test9 test10...
Test1 test2 test3 test4 test5 test6 test7 test8 test9 test10...
Test1 test2 test3 test4 test5 test6 test7 test8 test9 test10...
Test1 test2 test3 test4 test5 test6 test7 test8 test9 test10...
Test1 test2 test3 test4 test5 test6 test7 test8 test9 test10...
Test1 test2 test3 test4 test5 test6 test7 test8 test9 test10...
Test1 test2 test3 test4 test5 test6 test7 test8 test9 test10...
Test1 test2 test3 test4 test5 test6 test7 test8 test9 test10...
Test1 test2 test3 test4 test5 test6 test7 test8 test9 test10...
Test1 test2 test3 test4 test5 test6 test7 test8 test9 test10...
Test1 test2 test3 test4 test5 test6 test7 test8 test9 test10...
Test1 test2 test3 test4 test5 test6 test7 test8 test9 test10...
Test1 test2 test3 test4 test5 test6 test7 test8 test9 test10...
Test1 test2 test3 test4 test5 test6 test7 test8 test9 test10...
Test1 test2 test3 test4 test5 test6 test7 test8 test9 test10...
Test1 test2 test3 test4 test5 test6 test7 test8 test9 test10...
Test1 test2 test3 test4 test5 test6 test7 test8 test9 test10...
Test1 test2 test3 test4 test5 test6 test7 test8 test9 test10...
Test1 test2 test3 test4 test5 test6 test7 test8 test9 test10...
Test1 test2 test3 test4 test5 test6 test7 test8 test9 test10...
Test1 test2 test3 test4 test5 test6 test7 test8 test9 test10...
Test1 test2 test3 test4 test5 test6 test7 test8 test9 test10...
Test1 test2 test3 test4 test5 test6 test7 test8 test9 test10...
Test1 test2 test3 test4 test5 test6 test7 test8 test9 test10...
Test1 test2 test3 test4 test5 test6 test7 test8 test9 test10...
Test1 test2 test3 test4 test5 test6 test7 test8 test9 test10...
Test1 test2 test3 test4 test5 test6 test7 test8 test9 test10...
Test1 test2 test3 test4 test5 test6 test7 test8 test9 test10...
Test1 test2 test3 test4 test5 test6 test7 test8 test9 test10...
Test1 test2 test3 test4 test5 test6 test7 test8 test9 test10...
Test1 test2 test3 test4 test5 test6 test7 test8 test9 test10...
Test1 test2 test3 test4 test5 test6 test7 test8 test9 test10...
Test1 test2 test3 test4 test5 test6 test7 test8 test9 test10...
Test1 test2 test3 test4 test5 test6 test7 test8 test9 test10...
Test1 test2 test3 test4 test5 test6 test7 test8 test9 test10...
Test1 test2 test3 test4 test5 test6 test7 test8 test9 test10...
Test1 test2 test3 test4 test5 test6 test7 test8 test9 test10...
Test1 test2 test3 test4 test5 test6 test7 test8 test9 test10...
Test1 test2 test3 test4 test5 test6 test7 test8 test9 test10...
Test1 test2 test3 test4 test5 test6 test7 test8 test9 test10...
Test1 test2 test3 test4 test5 test6 test7 test8 test9 test10...
Test1 test2 test3 test4 test5 test6 test7 test8 test9 test10...
Test1 test2 test3 test4 test5 test6 test7 test8 test9 test10...
Test1 test2 test3 test4 test5 test6 test7 test8 test9 test10...
Test1 test2 test3 test4 test5 test6 test7 test8 test9 test10...
Test1 test2 test3 test4 test5 test6 test7 test8 test9 test10...
Test1 test2 test3 test4 test5 test6 test7 test8 test9 test10...
Test1 test2 test3 test4 test5 test6 test7 test8 test9 test10...
Test1 test2 test3 test4 test5 test6 test7 test8 test9 test10...
Test1 test2 test3 test4 test5 test6 test7 test8 test9 test10...
Test1 test2 test3 test4 test5 test6 test7 test8 test9 test10...
Test1 test2 test3 test4 test5 test6 test7 test8 test9 test10...
Test1 test2 test3 test4 test5 test6 test7 test8 test9 test10...
Test1 test2 test3 test4 test5 test6 test7 test8 test9 test10...
Test1 test2 test3 test4 test5 test6 test7 test8 test9 test10...
Test1 test2 test3 test4 test5 test6 test7 test8 test9 test10...
Test1 test2 test3 test4 test5 test6 test7 test8 test9 test10...
Test1 test2 test3 test4 test5 test6 test7 test8 test9 test10...
Test1 test2 test3 test4 test5 test6 test7 test8 test9 test10...
Test1 test2 test3 test4 test5 test6 test7 test8 test9 test10...
Test1 test2 test3 test4 test5 test6 test7 test8 test9 test10...
Test1 test2 test3 test4 test5 test6 test7 test8 test9 test10...
Test1 test2 test3 test4 test5 test6 test7 test8 test9 test10...
Test1 test2 test3 test4 test5 test6 test7 test8 test9 test10...
Test1 test2 test3 test4 test5 test6 test7 test8 test9 test10...
Test1 test2 test3 test4 test5 test6 test7 test8 test9 test10...
Test1 test2 test3 test4 test5 test6 test7 test8 test9 test10...
Test1 test2 test3 test4 test5 test6 test7 test8 test9 test10...
Test1 test2 test3 test4 test5 test6 test7 test8 test9 test10...
Test1 test2 test3 test4 test5 test6 test7 test8 test9 test10...
Test1 test2 test3 test4 test5 test6 test7 test8 test9 test10...
Test1 test2 test3 test4 test5 test6 test7 test8 test9 test10...
Test1 test2 test3 test4 test5 test6 test7 test8 test9 test10...
Test1 test2 test3 test4 test5 test6 test7 test8 test9 test10...
Test1 test2 test3 test4 test5 test6 test7 test8 test9 test10...
Test1 test2 test3 test4 test5 test6 test7 test8 test9 test10...
Test1 test2 test3 test4 test5 test6 test7 test8 test9 test10...
Test1 test2 test3 test4 test5 test6 test7 test8 test9 test10...
Test1 test2 test3 test4 test5 test6 test7 test8 test9 test10...
Test1 test2 test3 test4 test5 test6 test7 test8 test9 test10...
Test1 test2 test3 test4 test5 test6 test7 test8 test9 test10...
Test1 test2 test3 test4 test5 test6 test7 test8 test9 test10...
Test1 test2 test3 test4 test5 test6 test7 test8 test9 test10...
Test1 test2 test3 test4 test5 test6 test7 test8 test9 test10...
Test1 test2 test3 test4 test5 test6 test7 test8 test9 test10...
Test1 test2 test3 test4 test5 test6 test7 test8 test9 test10...
Test1 test2 test3 test4 test5 test6 test7 test8 test9 test10...
Test1 test2 test3 test4 test5 test6 test7 test8 test9 test10...
Test1 test2 test3 test4 test5 test6 test7 test8 test9 test10...
Test1 test2 test3 test4 test5 test6 test7 test8 test9 test10...
Test1 test2 test3 test4 test5 test6 test7 test8 test9 test10...
Test1 test2 test3 test4 test5 test6 test7 test8 test9 test10...
Test1 test2 test3 test4 test5 test6 test7 test8 test9 test10...
Test1 test2 test3 test4 test5 test6 test7 test8 test9 test10...
Test1 test2 test3 test4 test5 test6 test7 test8 test9 test10...
Test1 test2 test3 test4 test5 test6 test7 test8 test9 test10...
Test1 test2 test3 test4 test5 test6 test7 test8 test9 test10...
Test1 test2 test3 test4 test5 test6 test7 test8 test9 test10...
Test1 test2 test3 test4 test5 test6 test7 test8 test9 test10...
Test1 test2 test3 test4 test5 test6 test7 test8 test9 test10...
Test1 test2 test3 test4 test5 test6 test7 test8 test9 test10...
Test1 test2 test3 test4 test5 test6 test7 test8 test9 test10...
Test1 test2 test3 test4 test5 test6 test7 test8 test9 test10...
Test1 test2 test3 test4 test5 test6 test7 test8 test9 test10...
Test1 test2 test3 test4 test5 test6 test7 test8 test9 test10...
Test1 test2 test3 test4 test5 test6 test7 test8 test9 test10...
Test1 test2 test3 test4 test5 test6 test7 test8 test9 test10...
Test1 test2 test3 test4 test5 test6 test7 test8 test9 test10...
Test1 test2 test3 test4 test5 test6 test7 test8 test9 test10...
Test1 test2 test3 test4 test5 test6 test7 test8 test9 test10...
Test1 test2 test3 test4 test5 test6 test7 test8 test9 test10...
Test1 test2 test3 test4 test5 test6 test7 test8 test9 test10...
Test1 test2 test3 test4 test5 test6 test7 test8 test9 test10...
Test1 test2 test3 test4 test5 test6 test7 test8 test9 test10...
Test1 test2 test3 test4 test5 test6 test7 test8 test9 test10...
Test1 test2 test3 test4 test5 test6 test7 test8 test9 test10...
Test1 test2 test3 test4 test5 test6 test7 test8 test9 test10...
Test1 test2 test3 test4 test5 test6 test7 test8 test9 test10...
Test1 test2 test3 test4 test5 test6 test7 test8 test9 test10...
Test1 test2 test3 test4 test5 test6 test7 test8 test9 test10...
Test1 test2 test3 test4 test5 test6 test7 test8 test9 test10...
Test1 test2 test3 test4 test5 test6 test7 test8 test9 test10...
Test1 test2 test3 test4 test5 test6 test7 test8 test9 test10...
Test1 test2 test3 test4 test5 test6 test7 test8 test9 test10...
Test1 test2 test3 test4 test5 test6 test7 test8 test9 test10...
Test1 test2 test3 test4 test5 test6 test7 test8 test9 test10...
Test1 test2 test3 test4 test5 test6 test7 test8 test9 test10...
Test1 test2 test3 test4 test5 test6 test7 test8 test9 test10...
Test1 test2 test3 test4 test5 test6 test7 test8 test9 test10...
Test1 test2 test3 test4 test5 test6 test7 test8 test9 test10...
Test1 test2 test3 test4 test5 test6 test7 test8 test9 test10...
Test1 test2 test3 test4 test5 test6 test7 test8 test9 test10...
Test1 test2 test3 test4 test5 test6 test7 test8 test9 test10...
Test1 test2 test3 test4 test5 test6 test7 test8 test9 test10...
Test1 test2 test3 test4 test5 test6 test7 test8 test9 test10...
Test1 test2 test3 test4 test5 test6 test7 test8 test9 test10...
Test1 test2 test3 test4 test5 test6 test7 test8 test9 test10...
Test1 test2 test3 test4 test5 test6 test7 test8 test9 test10...
Test1 test2 test3 test4 test5 test6 test7 test8 test9 test10...
Test1 test2 test3 test4 test5 test6 test7 test8 test9 test10...
Test1 test2 test3 test4 test5 test6 test7 test8 test9 test10...
Test1 test2 test3 test4 test5 test6 test7 test8 test9 test10...
Test1 test2 test3 test4 test5 test6 test7 test8 test9 test10...
Test1 test2 test3 test4 test5 test6 test7 test8 test9 test10...
Test1 test2 test3 test4 test5 test6 test7 test8 test9 test10...
Test1 test2 test3 test4 test5 test6 test7 test8 test9 test10...
Test1 test2 test3 test4 test5 test6 test7 test8 test9 test10...
Test1 test2 test3 test4 test5 test6 test7 test8 test9 test10...
Test1 test2 test3 test4 test5 test6 test7 test8 test9 test10...
Test1 test2 test3 test4 test5 test6 test7 test8 test9 test10...
Test1 test2 test3 test4 test5 test6 test7 test8 test9 test10...
Test1 test2 test3 test4 test5 test6 test7 test8 test9 test10...
Test1 test2 test3 test4 test5 test6 test7 test8 test9 test10...
Test1 test2 test3 test4 test5 test6 test7 test8 test9 test10...
Test1 test2 test3 test4 test5 test6 test7 test8 test9 test10...
Test1 test2 test3 test4 test5 test6 test7 test8 test9 test10...
Test1 test2 test3 test4 test5 test6 test7 test8 test9 test10...
Test1 test2 test3 test4 test5 test6 test7 test8 test9 test10...
Test1 test2 test3 test4 test5 test6 test7 test8 test9 test10...
Test1 test2 test3 test4 test5 test6 test7 test8 test9 test10...
Test1 test2 test3 test4 test5 test6 test7 test8 test9 test10...
Test1 test2 test3 test4 test5 test6 test7 test8 test9 test10...
Test1 test2 test3 test4 test5 test6 test7 test8 test9 test10...
Test1 test2 test3 test4 test5 test6 test7 test8 test9 test10...
Test1 test2 test3 test4 test5 test6 test7 test8 test9 test10...
Test1 test2 test3 test4 test5 test6 test7 test8 test9 test10...
Test1 test2 test3 test4 test5 test6 test7 test8 test9 test10...
Test1 test2 test3 test4 test5 test6 test7 test8 test9 test10...
Test1 test2 test3 test4 test5 test6 test7 test8 test9 test10...
Test1 test2 test3 test4 test5 test6 test7 test8 test9 test10...
Test1 test2 test3 test4 test5 test6 test7 test8 test9 test10...
Test1 test2 test3 test4 test5 test6 test7 test8 test9 test10...
Test1 test2 test3 test4 test5 test6 test7 test8 test9 test10...
Test1 test2 test3 test4 test5 test6 test7 test8 test9 test10...
Test1 test2 test3 test4 test5 test6 test7 test8 test9 test10...
Test1 test2 test3 test4 test5 test6 test7 test8 test9 test10...
Test1 test2 test3 test4 test5 test6 test7 test8 test9 test10...
Test1 test2 test3 test4 test5 test6 test7 test8 test9 test10...
Test1 test2 test3 test4 test5 test6 test7 test8 test9 test10...
Test1 test2 test3 test4 test5 test6 test7 test8 test9 test10...
Test1 test2 test3 test4 test5 test6 test7 test8 test9 test10...
Test1 test2 test3 test4 test5 test6 test7 test8 test9 test10...
Test1 test2 test3 test4 test5 test6 test7 test8 test9 test10...
Test1 test2 test3 test4 test5 test6 test7 test8 test9 test10...
Test1 test2 test3 test4 test5 test6 test7 test8 test9 test10...
Test1 test2 test3 test4 test5 test6 test7 test8 test9 test10...
Test1 test2 test3 test4 test5 test6 test7 test8 test9 test10...
Test1 test2 test3 test4 test5 test6 test7 test8 test9 test10...
Test1 test2 test3 test4 test5 test6 test7 test8 test9 test10...
Test1 test2 test3 test4 test5 test6 test7 test8 test9 test10...
Test1 test2 test3 test4 test5 test6 test7 test8 test9 test10...
Test1 test2 test3 test4 test5 test6 test7 test8 test9 test10...
Test1 test2 test3 test4 test5 test6 test7 test8 test9 test10...
Test1 test2 test3 test4 test5 test6 test7 test8 test9 test10...
Test1 test2 test3 test4 test5 test6 test7 test8 test9 test10...
Test1 test2 test3 test4 test5 test6 test7 test8 test9 test10...
Test1 test2 test3 test4 test5 test6 test7 test8 test9 test10...
Test1 test2 test3 test4 test5 test6 test7 test8 test9 test10...
Test1 test2 test3 test4 test5 test6 test7 test8 test9 test10...
Test1 test2 test3 test4 test5 test6 test7 test8 test9 test10...
Test1 test2 test3 test4 test5 test6 test7 test8 test9 test10...
Test1 test2 test3 test4 test5 test6 test7 test8 test9 test10...
Test1 test2 test3 test4 test5 test6 test7 test8 test9 test10...
Test1 test2 test3 test4 test5 test6 test7 test8 test9 test10...
Test1 test2 test3 test4 test5 test6 test7 test8 test9 test10...
Test1 test2 test3 test4 test5 test6 test7 test8 test9 test10...
Test1 test2 test3 test4 test5 test6 test7 test8 test9 test10...
Test1 test2 test3 test4 test5 test6 test7 test8 test9 test10...
Test1 test2 test3 test4 test5 test6 test7 test8 test9 test10...
Test1 test2 test3 test4 test5 test6 test7 test8 test9 test10...
Test1 test2 test3 test4 test5 test6 test7 test8 test9 test10...
Test1 test2 test3 test4 test5 test6 test7 test8 test9 test10...
Test1 test2 test3 test4 test5 test6 test7 test8 test9 test10...
Test1 test2 test3 test4 test5 test6 test7 test8 test9 test10...
Test1 test2 test3 test4 test5 test6 test7 test8 test9 test10...
Test1 test2 test3 test4 test5 test6 test7 test8 test9 test10...
Test1 test2 test3 test4 test5 test6 test7 test8 test9 test10...
Test1 test2 test3 test4 test5 test6 test7 test8 test9 test10...
Test1 test2 test3 test4 test5 test6 test7 test8 test9 test10...
Test1 test2 test3 test4 test5 test6 test7 test8 test9 test10...
Test1 test2 test3 test4 test5 test6 test7 test8 test9 test10...
Test1 test2 test3 test4 test5 test6 test7 test8 test9 test10...
Test1 test2 test3 test4 test5 test6 test7 test8 test9 test10...
Test1 test2 test3 test4 test5 test6 test7 test8 test9 test10...
Test1 test2 test3 test4 test5 test6 test7 test8 test9 test10...
Test1 test2 test3 test4 test5 test6 test7 test8 test9 test10...
Test1 test2 test3 test4 test5 test6 test7 test8 test9 test10...
Test1 test2 test3 test4 test5 test6 test7 test8 test9 test10...
Test1 test2 test3 test4 test5 test6 test7 test8 test9 test10...
Test1 test2 test3 test4 test5 test6 test7 test8 test9 test10...
Test1 test2 test3 test4 test5 test6 test7 test8 test9 test10...
Test1 test2 test3 test4 test5 test6 test7 test8 test9 test10...
Test1 test2 test3 test4 test5 test6 test7 test8 test9 test10...
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

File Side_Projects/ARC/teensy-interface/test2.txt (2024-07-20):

Test1 test2 test3 test4 test5 test6 test7 test8 test9.

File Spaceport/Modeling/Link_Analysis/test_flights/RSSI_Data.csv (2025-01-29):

RSSI
-40
-41
-45
-46
-44
-43
-45
-42
-43
-44
-46
-46
-47
-50
-51
-45
-63
-78
-60
-63
-54
-49
-48
-53
-47
-47
-47
-47
-47
-47
-46
-46
-47
-46
-47
-47
-47
-48
-48
-47
-47
-47
-48
-48
-48
-47
-48
-46
-47
-47
-47
-47
-47
-47
-47
-46
-46
-46
-46
-46
-47
-46
-47
-47
-47
-47
-47
-47
-47
-47
-47
-47
-46
-47
-47
-47
-47
-47
-47
-46
-47
-47
-47
-47
-46
-46
-46
-46
-46
-47
-47
-47
-47
-47
-46
-46
-48
-46
-46
-47
-47
-47
-47
-48
-47
-47
-47
-47
-46
-47
-47
-48
-47
-47
-48
-48
-47
-46
-46
-46
-46
-46
-46
-46
-47
-47
-47
-47
-47
-47
-46
-47
-46
-46
-47
-47
-48
-46
-47
-47
-46
-47
-46
-47
-47
-47
-47
-48
-47
-45
-48
-48
-48
-47
-47
-47
-47
-60
-56
-63
-59
-66
-58
-59
-67
-62
-60
-65
-76
-60
-70
-59
-64
-57
-55
-60
-56
-58
-58
-70
-56
-60
-53
-67
-57
-55
-55
-59
-51
-55
-67
-56
-55
-53
-53
-59
-53
-54
-57
-54
-48
-53
-48
-52
-46
-43
-46
-46
-43
-57
-48
-43
-50
-87
-94
-82
-82
-84
-84
-80
-80
-81
-87
-83
-78
-77
-81
-83
-82
-82
-84
-79
-77
-82
-81
-82
-83
-82
-77
-76
-75
-65
-64
-71
-70

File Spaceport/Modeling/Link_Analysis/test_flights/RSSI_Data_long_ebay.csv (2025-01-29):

RSSI
-36
-41
-39
-39
-39
-40
-40
-40
-42
-39
-38
-38
-38
-37
-38
-38
-34
-42
0
-44
-44
-44
-44
-45
-45
-45
-45
-45
-44
-43
-46
-44
-44
-38
0
-42
-47
-46
-43
-45
-44
-44
-45
-43
-43
-43
-43
-44

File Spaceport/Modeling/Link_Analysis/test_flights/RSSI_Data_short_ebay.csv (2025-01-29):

RSSI
-38
-54
-42
-43
-43
-39
-39
-39
-39
-39
-40
-43
-40
-41
-47
0
-38
-37
-36
-37
-37
-37
-37
-37
-38
-37
-37
-38
-37
-38
-38
-38
-37
-39
-51
0
-45
-50
-45
-46
-45
-46
-46
-48
-46
-46
-46
-46
-45
-46
-45

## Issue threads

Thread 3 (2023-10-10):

Create MAX-M10S Subcircuit

varun-un, 2023-10-10:
Create a full PCB in KiCad for the MAX-M10S GPS component. This involves creating both the schematic and the physical PCB structure for a subcircuit PCB, which would have just the sensor and the Teensy.

Create the schematic based on the component datasheet, as well as considering what pins are needed based on the communication protocol. Pins that start with a V will be used to supply the component voltage and GND is needed to ground the component, but if I2C is used, for example, SDA and SCL, along possibly other pins will be needed as well. Research which pins will be needed, adding a 'No Connection' flag to all those not needed. Also include any components (resistors, diodes, capacitors, etc) that may be needed between wiring routes. For example, each sensor will probably need a small decoupling capacitor placed on either the voltage or ground line. Specifically for the GPS, there will be certain pins and lines that will need to be routed to the antenna, which is how the GPS receives signals from the satellites. These lines may be denoted by some reference to GNSS constellations or radio in the datasheet.

Use the Teensy 4.1 pinout diagram to see where in the Teensy each outgoing line would connect, and wire them up to a connector component, that will just show up as a couple holes on the PCB that we can use wires to connect the Teensy to.

If the sensor IC chip doesn't already exist in KiCad's library, a custom symbol and footprint will need to be made.

- [ ]  Create schematic of sensor
- [ ]  Create PCB on KiCad
- [ ]  Research radio filters (high pass, low pass)
- [ ]  Research and implement antennas into subcircuit

MAX-M10S Datasheet: https://www.mouser.com/datasheet/2/1025/MAX_M10S_DataSheet_UBX_20035208-3180723.pdf
Teensy Pinout: [Teensy and Teensy++ Pinouts, for C language and Arduino Software](https://www.pjrc.com/teensy/pinout.html)

varun-un, 2023-12-02:
Resolved with MAX-M10S subcircuits being completed.
Merged with pull requests #22 and #23

Closed 2023-12-02.

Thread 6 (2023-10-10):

Write BNO055 library-based code

varun-un, 2023-10-10:
Write the code for the BNO055 sensor, within the code section of this repository. You can use existing libraries for this sensor for when it is a breakout board to simplify operations and readings. Write two files in the [`/src` folder](https://github.com/Terrapin-Rocket-Team/SRAD_Avionics/tree/main/Spaceport/23-24/Code/Teensy-Based%20Avionics/src), one header file and one `.cpp` file to include the specific implementation for the sensor.

Make sure to use an object-oriented approach for developing this sensor's code, and inherit the functions from the virtual superclass for the specific sensor type, which you can find in the [`/include` folder](https://github.com/Terrapin-Rocket-Team/SRAD_Avionics/tree/main/Spaceport/23-24/Code/Teensy-Based%20Avionics/include). For the BNO055, this would be the [`IMU` superclass](https://github.com/Terrapin-Rocket-Team/SRAD_Avionics/blob/main/Spaceport/23-24/Code/Teensy-Based%20Avionics/include/IMU.h). Make sure that your files implement all the listed functions.

Example Adafruit library: [GitHub - adafruit/Adafruit_BNO055: Unified sensor driver for the Adafruit BNO055 orientation sensor breakout](https://github.com/adafruit/Adafruit_BNO055/tree/master)

Closed 2024-02-07.

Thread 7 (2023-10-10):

Write RTC library-based code

varun-un, 2023-10-10:
Write the code for the RTC, or real-time clock sensor, within the code section of this repository. The specific component may be the DS3231, but talk with whoever is doing the subcircuit for the RTC first to make sure. You can use existing libraries for this sensor for when it is a breakout board to simplify operations and readings. Write two files in the [`/src` folder](https://github.com/Terrapin-Rocket-Team/SRAD_Avionics/tree/main/Spaceport/23-24/Code/Teensy-Based%20Avionics/src), one header file and one `.cpp` file to include the specific implementation for the sensor.

Make sure to use an object-oriented approach for developing this sensor's code, and inherit the functions from the virtual superclass for the specific sensor type, which you can find in the [`/include` folder](https://github.com/Terrapin-Rocket-Team/SRAD_Avionics/tree/main/Spaceport/23-24/Code/Teensy-Based%20Avionics/include). For the RTC, this would be the [`RTC` superclass](https://github.com/Terrapin-Rocket-Team/SRAD_Avionics/blob/main/Spaceport/23-24/Code/Teensy-Based%20Avionics/include/RTC.h). Make sure that your files implement all the listed functions.

Example Adafruit library: [Adafruit DS3231 Arduino Usage Guide](https://learn.adafruit.com/adafruit-ds3231-precision-rtc-breakout/arduino-usage).

Closed 2024-01-31.

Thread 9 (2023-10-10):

Write software-in-the-loop testing methods

varun-un, 2023-10-10:
Look into developing/writing functions that can act as software-in-the-loop testing services, that would inject pre-recorded data into a sensor’s functions within the Teensy to mimic that sensor recording real flight data to statically test the system.

varun-un, 2024-02-29:
Completed by PR #58, and explained in [this comment](https://github.com/Terrapin-Rocket-Team/SRAD_Avionics/issues/54#issuecomment-1949630370)

Closed 2024-02-29.

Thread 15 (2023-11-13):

Create Tester Class/Functionality

varun-un, 2023-11-13:
There are two approaches to how one could build out testing functionality, so it's up to the coder which approach to use. These files should be added to the `test\` folder within the codebase:

- Create a C++ file for each sensor you want to test, with each file containing a `setup()` and `loop()` function, as per the Arduino framework's guidelines. Then, start the Serial in the setup and call the sensor's methods in the file, printing out the outputs to the serial console so that while testing, the values can be seen in real-time to validate whether or not they're as they should be
- Create a `Tester` class that works with each sensor type. It will call the sensor's basic methods when connected to it, and serves as a simplified `State` class for the sake of testing the _Sensor_-_Teensy_ system in isolation with the hardware. It should print the detected data to the Serial monitor for data verification.

Closed 2024-01-09.

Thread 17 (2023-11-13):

Formal Testing Plans for Charge Deployment Circuit

varun-un, 2023-11-13:
Write up a formal document(s) detailing how we're going to test the charge deployment circuit, working our way up from simple continuity tests to current tests, and so on. Can use the the template specified [here](https://docs.google.com/document/d/1Z-pRsuiEbraIZX35bwrJ8E5ElYY9juLDjcs0f0KBtkQ/edit?usp=sharing).

Closed 2025-09-18.

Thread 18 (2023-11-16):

Add extra kicad files to gitignore

jhauerst, 2023-11-16:
There are a bunch of autogenerated kicad files that don't need to be committed, so they should be added to the gitignore for convenience. These include *.kicad_prl files, the fp_info_cache file, and the backups folder and possibly others.

DrewBrandt, 2024-02-14:
As I understand it, gerber files are not part of the design and do not need to be source-controlled. Is that right? Similarly, I read that files prepended with ~ are autosave files. Is that also right? Here are the changes I've made.

[Blame for .gitignore](https://github.com/Terrapin-Rocket-Team/SRAD_Avionics/blame/18-add-extra-kicad-files-to-gitignore/.gitignore)

I'll make a pull request if you agree with the changes.

Closed 2024-02-16.

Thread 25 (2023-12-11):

Trace through Arduino Library Code for BMP390

varun-un, 2023-12-11:
As we look to eventually transition from a Teensy 4.1 microcontroller, which uses the Arduino Framework, to an STM32-based ARM chip, which is lower-level, we'll have to change much of the code for individual sensors to fit the new architecture of the computer's main chip. This means that the original code that we currently have, which uses the sensor's Arduino libraries, will no longer work.

What we'll have to do is now go inside the library's code, and start to try to understand how it works, and how this library can be modified for use with the STM32 chip. The tasks for this are:

- [ ] Go into the library's code and understand the different files and hierarchical structure of the code
- [ ] Look at the sensor's datasheet and see what registers/pins the code would need to write to and read from to help understand the library as well as how the sensor works
- [ ] Identify key lines/code segments that are microcontroller-specific, and would have to be changed for the STM
- [ ] Mark down these lines in a document (or just add them as a comment on here)
- [ ] Research alternative libraries that may transition better or even work by default with the STM32

[BMP390 Datasheet](https://www.bosch-sensortec.com/media/boschsensortec/downloads/datasheets/bst-bmp390-ds002.pdf)
[BMP390 Library](https://github.com/adafruit/Adafruit_BMP3XX)
[STM32 Datasheet](https://www.st.com/content/ccc/resource/technical/document/datasheet/0d/93/e0/d7/77/bf/4c/54/CD00210843.pdf/files/CD00210843.pdf/jcr:content/translations/en.CD002108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)

varun-un, 2023-12-11:
Look at possibly using this library: https://github.com/BoschSensortec/BMP3-Sensor-API
and modifying the wrapper [`common.c`](https://github.com/BoschSensortec/BMP3-Sensor-API/blob/master/examples/common/common.c) to work with STM32F103

Forum Posts about it: [Post 1](https://community.bosch-sensortec.com/t5/MEMS-sensors-forum/How-to-use-BMP388-with-STM32/td-p/50411), [Post 2](https://community.bosch-sensortec.com/t5/MEMS-sensors-forum/How-to-adapt-Bosch-Sensor-API-s-to-use-with-STM32/m-p/50509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)

Closed 2024-05-30.

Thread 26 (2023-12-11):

Trace Through Arduino Library Code for BNO055

varun-un, 2023-12-11:
As we look to eventually transition from a Teensy 4.1 microcontroller, which uses the Arduino Framework, to an STM32-based ARM chip, which is lower-level, we'll have to change much of the code for individual sensors to fit the new architecture of the computer's main chip. This means that the original code that we currently have, which uses the sensor's Arduino libraries, will no longer work.

What we'll have to do is now go inside the library's code, and start to try to understand how it works, and how this library can be modified for use with the STM32 chip. The tasks for this are:

- [ ] Go into the library's code and understand the different files and hierarchical structure of the code
- [ ] Look at the sensor's datasheet and see what registers/pins the code would need to write to and read from to help understand the library as well as how the sensor works
- [ ] Identify key lines/code segments that are microcontroller-specific, and would have to be changed for the STM
- [ ] Mark down these lines in a document (or just add them as a comment on here)
- [ ] Research alternative libraries that may transition better or even work by default with the STM32

[BNO055 Datasheet](https://cdn-shop.adafruit.com/datasheets/BST_BNO055_DS000_12.pdf)
[BNO055 Library](https://github.com/adafruit/Adafruit_BNO055)
[STM32 Datasheet](https://www.st.com/content/ccc/resource/technical/document/datasheet/0d/93/e0/d7/77/bf/4c/54/CD00210843.pdf/files/CD00210843.pdf/jcr:content/translations/en.CD002108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)

Closed 2024-05-30.

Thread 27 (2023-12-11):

Trace Through Arduino Library Code for MAX-M10S

varun-un, 2023-12-11:
As we look to eventually transition from a Teensy 4.1 microcontroller, which uses the Arduino Framework, to an STM32-based ARM chip, which is lower-level, we'll have to change much of the code for individual sensors to fit the new architecture of the computer's main chip. This means that the original code that we currently have, which uses the sensor's Arduino libraries, will no longer work.

What we'll have to do is now go inside the library's code, and start to try to understand how it works, and how this library can be modified for use with the STM32 chip. The tasks for this are:

- [ ] Go into the library's code and understand the different files and hierarchical structure of the code
- [ ] Look at the sensor's datasheet and see what registers/pins the code would need to write to and read from to help understand the library as well as how the sensor works
- [ ] Identify key lines/code segments that are microcontroller-specific, and would have to be changed for the STM
- [ ] Mark down these lines in a document (or just add them as a comment on here)
- [ ] Research alternative libraries that may transition better or even work by default with the STM32

[MAX-M10S Datasheet](https://content.u-blox.com/sites/default/files/MAX-M10S_DataSheet_UBX-20035208.pdf)
[MAX-M10S Library](https://github.com/sparkfun/SparkFun_u-blox_GNSS_v3)
[STM32 Datasheet](https://www.st.com/content/ccc/resource/technical/document/datasheet/0d/93/e0/d7/77/bf/4c/54/CD00210843.pdf/files/CD00210843.pdf/jcr:content/translations/en.CD002108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)

Closed 2024-05-30.

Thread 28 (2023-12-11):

Test the patch antenna and consider filtering circuits

varun-un, 2023-12-11:
- [ ] Learn how to use the oscilloscope and/or the NanoVNA to be able to assess the efficiency and other important factors for the chip antenna for the MAX-M10S
- [ ] If needed, find ways to modify the antenna and surrounding environments to better it
- [x] Research and pick a radio filtering circuit (high pass, low pass, etc) to fix the GPS signal if needed.

[Antenna Datasheet](https://www.mouser.com/datasheet/2/398/SGGP_12_4_A_02-3137490.pdf)

varun-un, 2024-04-08:
Know how to use NanoVNA for antenna SWR

Closed 2024-04-08.

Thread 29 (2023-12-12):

Integrate Breakout Boards into Unified Board

varun-un, 2023-12-12:
Create a unified PCB board that includes all of the circuits and components from each of the subcircuit breakout boards and Teensy master board. Should also include a buzzer, mounting holes, terminal block, and breakouts.

Also make sure that CSB, I2C_ADDR, and INT pins are properly pulled high/low if needed

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

varun-un, 2024-01-17:
Use this for trace width calculations: https://chemandy.com/calculators/coplanar-waveguide-with-ground-calculator.htm
.2mm trace width with .1mm dielectric thickness will give 50Ω impedance which is needed for RF_IN line to MAX-M10S

Closed 2024-01-18.

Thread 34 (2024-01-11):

Radio Code Improvements

jhauerst, 2024-01-11:
The radio code from #11 will also need to be updated to work with Raspberry Pi for transmitting live video, and Windows and MacOS machines, if possible, for receiving on the ground. This involves removing or finding an alternative for Arduino dependencies such as String, and testing the code on each platform. This will also be useful for the future transition to the STM32. This issue will also include the suggestions from #32.

- [x] Remove or find alternatives to Arduino libraries used in the Radio and RFM69HCW classes.
- [ ] Find alternatives or develop a custom implementation for Arduino libraries used in the RFM69 class.
     - [x] Find header files to replace Arduino.h
     - [ ] Make a replacement SPIClass for Raspberry Pi, Windows, and MacOS
- [x] Make an enum for type
- [x] Make a struct for APRSData

Closed 2024-02-11.

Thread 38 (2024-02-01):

Calculations for Low-Pass Filter

LShapir0, 2024-02-01:
Calculate values for resistor, capacitor and inductor for a low-pass filter for the MAX-M10s chip.

LShapir0, 2024-02-21:
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

L3 - 27 nH, 5%;
Recommended Inductors:
Murata LQG15H, LQW15A series
Johanson Technology L-07W series
Any other inductor with impedance >500 Ω at GNSS
frequency and current rating above 300 mA.
R8 - 10 Ω, 5%, 0.25 W
C14 - 10 nF, 10%, 16 V, X7R

LShapir0, 2024-02-22:
Since we don't have a 10nH inductor in stock, the best bet is to use the 10nH inductor.

varun-un, 2024-02-26:
Unified Board v1.1 assembled with `LP_R` as 10Ω, `LP_C` as 10nF, and `FB1` as 68nH

Closed 2024-02-29.

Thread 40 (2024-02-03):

Integrate Kalman Filter

varun-un, 2024-02-03:
Integrate the Kalman Filter code into the `State.cpp` file in the `updateState()` function, where it would plug in to update the generic system variables.

Also, test the KF in C++ by feeding in past launch data to measure accuracy and it works (software-in-the-loop testing).

DrewBrandt, 2024-02-29:
Kalman filter appears to be working and mostly agrees with unfiltered data. The unfiltered data in this image has a slight error that caused the same data to be reported for 5 time values straight. This appears to have been a bug with the earlier version of the code. It is what causes the sudden jump to the right on the way up at about 350 meters.

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

varun-un, 2024-02-29:
The jump on the way up may also be due to airbrake, when they open their flaps on the way up, air rushes into the rocket body which changes the pressure which affects the barometer's readings, which in past data from both avionics and airbrake electronics has caused a little jump. As for the same data being reported 5 times, I don't really know but that's probably a bug

DrewBrandt, 2024-02-29:
My point was more that, had that slight jump not been there, the Kalman filter appears that it would have followed the line exactly, which may not be the intended behavior. That error is not in the data given to the system, only in the data recorded by it for the iteration that I was able to use for comparison.

Closed 2024-04-23.

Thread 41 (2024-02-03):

Modify GPS board to allow for mode selection

varun-un, 2024-02-03:
Certain u-blox GPS modules allow for mode selection (page 15 of the [MAX-M10S Integration Manual](https://content.u-blox.com/sites/default/files/MAX-M10S_IntegrationManual_UBX-20053088.pdf)), so try modifying the GPS schematic and breakout to allow us to select the `Airborne >4g` mode.

DrewBrandt, 2024-02-14:
This is all you need to do if we are using the arduino library and we get it to work:

```python
m10s.setDynamicModel(DYN_MODEL_AIRBORNE4g);
```

varun-un, 2024-02-14:
Does this work over i2c?

DrewBrandt, 2024-02-14:
It's from the m10s library, which appears to support both I2C and SPI. I'm pretty sure that if we get the GPS module to work with our current code/the sample code, then it will work with this command.

Closed 2024-03-04.

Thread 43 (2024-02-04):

Radio code RPi compatibility

jhauerst, 2024-02-04:
Write a header file that provides definitions for the Arduino dependencies of RFM69.h. This will allow the radio code to be used with the RPi's for live video. A library for using SPI on the RPi can be found [here](https://abyz.me.uk/rpi/pigpio/cif.html).

- [ ] Create a header file and modify RFM69.h to provide definitions for all the functions used by the library from Arduino.h
- [ ] Confirm that the RFM69HCW, Radio, RFM69, and APRSMsg files compile on a Raspberry Pi

jhauerst, 2024-02-29:
Closing as this issue is obsolete with the merging of #65 and has been replaced by #69.

Closed 2024-02-29.

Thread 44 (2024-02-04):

Implement radio encoders and decoders

jhauerst, 2024-02-04:
Implement missing encoders and/or decoders for each encoding type. These include the Video encoder, Video decoder, and Ground Station encoder. The Video encoder should encode a buffer of video data into a Base256 string (essentially as an unsigned char array). The Video decoder should decode a Base256 string into a buffer of video data. The Ground Station encoder should take a Ground Station data string (see RFM69HCW.h or ground station documentation for formatting) and encode it as a APRS message.

- [ ] Implement Video encoder
- [ ] Implement Video decoder
- [ ] Implement Ground Station encoder
- [ ] Suggest any additional encoders/decoders that could be useful

jhauerst, 2024-07-20:
Closing since this has mostly been completed by other issues and is more of an MMFS task now anyway.

Closed 2024-07-20.

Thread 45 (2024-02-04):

Fix data strings

jhauerst, 2024-02-04:
Looking at the launch data, there seems to be some missing columns of data, as well as a missing comma in the BMP390 data string. To correct these issues, implement a consistent method of formatting data strings across sensors and fix existing issues with the CSV output. Example launch data with these issues is [attached](https://github.com/Terrapin-Rocket-Team/SRAD_Avionics/files/14155152/datalog_32.csv).

- [x] Develop and implement a consistent data string format
- [x] Find and fix any remaining formatting issues with CSV data output

Closed 2024-02-27.

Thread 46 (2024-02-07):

Live video Raspberry Pi mount design

jhauerst, 2024-02-07:
The live video hardware (Raspberry Pi, camera, battery, power board, and radio) will need a mount in the ebay. The mount will be 3D printed, and should be as small and sturdy as possible. Currently, the battery has not been chosen and the power board has not been designed, but the battery will most likely be similar to [this](https://power.tenergy.com/tenergy-nimh-6v-2000mah-side-by-side-receiver-battery-pack-w-hitec-connector-for-rc-aircrafts/). The power board will be mounted on the RPi header pins if possible, but may need to be mounted elsewhere if clearance with the [RPi heatsink](https://www.adafruit.com/product/4341?gad_source=1) is an issue. The radio will likely be mounted on the power board in either situation. The [camera](https://www.amazon.com/Inno-Maker-Camera-Module-OV5647-Raspberry/dp/B07G9VLPZH) will need to be mounted so that it is positioned to look out of a hole in the side of the ebay, so it may get a separate mount.

Tasks:

- [ ] Design a mount that secures the Raspberry Pi and battery in the ebay
- [ ] Integrate a mount for the power board and camera if necessary
- [ ] 3D print the mount and test fit all components

DrewBrandt, 2024-04-23:
Closed at some point with development of current eBay design

Closed 2024-04-23.

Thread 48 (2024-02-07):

Look at BMP390 Issues

varun-un, 2024-02-07:
There are 2 primary issues with the BMP390 subcircuit/sensor that need looking at:

- [x] There are occasional issues with the breakout board and the sensor chip properly connecting to the I2C bus. On occasion, after working fine, the sensor will say it's unable to be connected to the I2C bus, typically triggered by another device a to ttempting to connect to the bus. A potential fix is to then explicitly pull the `CS` (chip select) pin on the BMP390 to `3.3V` to reset it, indicating that this could be a potential issue with how the `CS` pin is pulled.
- [x] Flight data for February reads in BNO055 values, however, even when the BNO055 indicates that the rocket is in-flight, the BMP390 still reads altitudes less than 20ft. Test and debug this issue.

Closed 2024-02-26.

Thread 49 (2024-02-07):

Fix the Unified Board

varun-un, 2024-02-07:
Look to see if there are any potential issues or bugs with the Unified Board schematic and PCB. The board would not let sensors properly connect to the I2C bus, and while it could be a problem associated with the physical assembly and bridged pads within the hardware, it also could be a flaw of the board itself.

Many people should look over this.

Also, add the following features:

- [x] Power circuitry to have a screw switch terminal block
- [x] Fix buzzer feed line
- [ ] Standardize I2C pullup resistors (if needed)
- [x] Add SPI breakouts for radio systems (talk to @jhauerst)
- [ ] Implement LP Filter
- [x] Implement GPS breakout changes

jhauerst, 2024-02-15:
@varun-un I took a look at the radio mount on the unified board. It looks good except there needs to be a connection for the INT pin (4 on the schematic, just above SCK), and the RST pin (9 on the schematic, at the bottom). Both can be connected to any IO pin on the teensy. Also just keep in mind that the antenna will be facing to the right (from the board orientation in the schematic) the way the mount is currently oriented.

More general notes:
- If C11 is a decoupling capacitor for the teensy it should probably be moved physically closer to the VIN, maybe above the teensy
- I don't think the wiring is right for the BMP390, the capacitors need to be physically connected to particular pins, this may help explain some of the issues we were having connecting.
- It seems like the same issue might apply to the BNO055, all of the capacitors are connected to one VIN, while other VIN pins don't have any. But, I didn't do the circuit for that sensor, so I'm not sure.

I don't have time to look over it completely right now, so I'll and another comment if I see anything else

jhauerst, 2024-02-15:
More comments:
- It's probably best if the pullup resistor for SDA is actually on the SDA line that goes out to all the sensors. It probably doesn't make a difference, but I feel like it's better to be safe than risk having issues later
- It might be good to put a physical indicator of the MAX-M10S orientation so we don't solder wrong again
- The LED labelled IMU_LED seems to be connected to the GPS, while the GPS_LED does not seem to be connected to GPS power
- C8 seems to be a decoupling capacitor for the radio, but it does not seem to be connected to the radio, and only one pad seems to be connected.
- BMP I2C_ADDR should be pulled high (I think)

That's everything I could find, it also is a good idea to run the design rules check just to make sure there are not big issues.

varun-un, 2024-02-15:
Should `BMP_I2C_ADDR` be pulled high by default, so disconnect it from the teensy and just connect it to 3.3V like CS?

jhauerst, 2024-02-15:
> Should `BMP_I2C_ADDR` be pulled high by default, so disconnect it from the teensy and just connect it to 3.3V like CS?

For the default address (which I think is the one we are using), yes

Closed 2024-02-26.

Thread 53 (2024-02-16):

Update Readme with general information about how the codebase works to help with onboarding new members

DrewBrandt, 2024-02-16:
Having all information about the State class, the various data sensors we use (maybe with links to their data sheets or integration manuals) and our mission to move away from Arduino and into platform-agnostic code would be very helpful, speaking from experience.

DrewBrandt, 2024-03-04:
I have started working on this over on the Wiki tab. It's in early stages but hopefully the layout of it makes sense. GitHub's wiki features seem a bit lacking, so we may want to look for other hosting options in the future.

Closed 2024-06-23.

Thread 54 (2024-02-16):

Update State class and sensor classes to get rid of Arduino String and and C++ STL refrences

DrewBrandt, 2024-02-16:
In order to support moving to more portable code, the state class and related sensor classes should give their data in a format that can be used cross platform.

- [x] No more Arduino `String` class
- [x] No more C++ `std::xxxxx` code
- [x] **test for memory leaks in areas where memory is being dynamically allocated**

Edited Later:
- [ ] Update the RecordData library
- [x] Write tests that simulate sensors to do memory checks/formatting checks

DrewBrandt, 2024-02-16:
Ok I've written it all but it needs to be thoroughly tested. RecordData library should have all of its String references removes as well.

<sub>does this work?</sub>
- [ ] Update the RecordData library
- [ ] Write tests that simulate sensors to do memory checks/formatting checks
- [ ] Look to see if the RTC implementation can be brought more inline with the other sensors.
- [ ] Write a LightSensor class? Do we need to talk with Payload for that?

Because of the lack of current testing, I do not want to create a pull request. If you guys have time @varun-un and @jhauerst, can you take a look at it and let me know what you think?

DrewBrandt, 2024-02-16:
I've written tests on branch Tests-for-54. The tests also need to be tested, but the idea is to feed it fake data from a past launch and see what it does.

DrewBrandt, 2024-02-17:
That other branch is now merged with the one for this issue. It includes a test folder that can be used to test the state class (and kalman filter). To use it, switch your platfomio environment away from "Default" and into `env:teensy4.1_TEST_STATE`

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

That will cause the compiler to ignore `main.cpp` and instead load `TestState.cpp` as the main. From there you can run the code on the teensy, then, when the light turns solid, run the `SendData.py` script to start sending data to it via serial.

It then listens for a response from the teensy about what state it THINKS its in, before sending more data. It compiles every message the teensy sends it about its state in `test_results.csv`.

---

I checked as best as I could for memory leaks, but there do not appear to be any. I would like someone else \*cough\* @varun-un  \*cough\* to take a look and tell me what they think.

The main idea behind this was to make the code more portable, which I strongly feel has been accomplished. The sensors themselves still need to be addressed, and the test will only run on an Arduino, but it's a first step.

---

PS. Install Colorama (`pip install colorama`) to use the python script. The colors make it much easier to compare between sent and received messages.

Closed 2024-02-27.

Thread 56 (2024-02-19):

Design Ground Radio Receiver Board

jhauerst, 2024-02-19:
To receive radio signals on the ground, there will need to be a board that connects the RFM69HCW radios to a Teensy 4.1, that will then transfer the radio data to a computer. For this purpose, a PCB should be developed that connects multiple radios to a Teensy so that a single board can support receiving both telemetry and live video transmissions. The radios will connect to the Teensy using the same SPI interface, and the PCB will essentially serve as a mount that provides power and connections to the Teensy for the radios.

Tasks:
- [x] Develop a PCB that connects at least three radios to a Teensy 4.1
- [x] Document the Teensy SPI bus used, as well as the CS pins used for each radio
- [ ] Test that a Teensy can transfer about 700kpbs over USB and document results
- [ ] Cad casing piece to hold the receiver board

Notes:
See the unified board or the live video power board for the radio pin connections.

dshi0322, 2024-02-23:
Note: Teensy max 250ma draw and the radio can draw from 50ma to 150ma

dshi0322, 2024-02-29:
Pin 29-27 has CS1-3 respectively

dshi0322, 2024-02-29:
Pins 12 MOSI, 13 MISO, 34 SCK

Closed 2024-03-24.

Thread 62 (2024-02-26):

Improve MAX-M10S code to reduce calls that fetch data from the chip

DrewBrandt, 2024-02-26:
In the MAX-M10S read_gps() code, it makes multiple calls that use i2c to fetch data from the chip. The code should be reworked so that it only fetches that data once and stores it in a local variable for reuse.

Closed 2024-03-04.

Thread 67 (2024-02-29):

Design On-The-Ground Radio Teensy Code

varun-un, 2024-02-29:
This code should be able to synchronize and transmit the 3 streams of data from 2 live video sources and 1 telemetry source in real-time over Serial to a laptop's USB port for processing by the Ground Station. This should be done with minimal overhead and quick enough that all radio data gets transmitted seamlessly

varun-un, 2024-02-29:
Will also need Ground Station code developed in tandem to decipher and separate out the streams of data

jhauerst, 2024-08-22:
@varun-un I believe this code is completed, has it been merged in yet?

Closed 2024-08-22.

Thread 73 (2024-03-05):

Fix double pointer dereferencing issue that would ocour if some sensors are never added

DrewBrandt, 2024-03-05:
I am probably going to (again) switch how sensors are stored in the state class because while the way I did it for the last release is cool, it is unintuitive to use and has issues if you forget to call computer.addSensor() for one of the sensors.

DrewBrandt, 2024-03-08:
closed by #74

Closed 2024-03-08.

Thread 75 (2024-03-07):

BMP Oscillation Issue

DrewBrandt, 2024-03-07:
Whenever the radio transmits, the altimeter jumps up a number of feet. We know it has something to do with the radio waves as changing the antenna/ antenna orientation changes the amplitude of the oscillations. We don't know how to fix this.

If you or someone you know ~~has been diagnosed with mesothelioma~~ can help, please do.

DrewBrandt, 2024-06-23:
Closed because will most likely be using a COTS barometer for competitions

Closed 2024-06-23.

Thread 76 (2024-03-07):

Begin implementation of platform agnostic sensor code

DrewBrandt, 2024-03-07:
Following on from #25, #26, and #27, begin planning out what a portable flight code project would look like.

DrewBrandt, 2024-03-07:
I think this may take on the from of some kind of intermediary that we write that can detect the platform and use the appropriate low level libraries. I'm doing some research on it now.

DrewBrandt, 2024-03-07:
I expect this to be a long-term project that is basically on this branch for a few months. I'm going to re-arrange a few files and add some folders to this branch to make things a bit easier to manage as I change and test stuff.

DrewBrandt, 2024-07-06:
Update: Code compiles and runs on the STM32 dev board we got. Next step is designing a custom STM board, i.e. #83

varun-un, 2024-09-10:
Closing as this becomes a more MMFS issue

Closed 2024-09-10.

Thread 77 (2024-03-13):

Fix Kalman Filter to be dynamic and consistent

varun-un, 2024-03-13:
Make the Kalman Filter changes talked about on Friday to be more consistent with Payload and to be more expandable (in theory).

Also make the changes in the Avionics code to then implement this modified Kalman Filter library (with config file of functions and so on)

abhi-senthilkumar, 2024-03-13:
Talking to Avi about this

Closed 2024-04-23.

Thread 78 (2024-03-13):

Look into higher frequency telemetry

varun-un, 2024-03-13:
May be as simple as changing the `radioTimer` interval if statement to be not 2000, in which case this issue can be closed.

But if not, make the necessary changes and make it easily variable, as well as potentially benchmark the radio transmissions to ensure it doesn't slow down the main loop.

Closed 2024-04-23.

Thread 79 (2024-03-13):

Altitude jumping issue

varun-un, 2024-03-13:
When testing at the launch, on occasion when holding up the board, the reported altitude by the ground station was that in the hundreds of feet (obviously inaccurate). Replicate and then determine the cause of this issue, whether it is in the BMP itself, the State sensor processing code, the APRS packets, or in the regex parsing of the Ground Station itself.

varun-un, 2024-04-08:
Temp fix - move radio antenna to other side of the board

Closed 2024-04-08.

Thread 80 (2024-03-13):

Redesign E-Bay sled

varun-un, 2024-03-13:
Modify the CAD for the e-bay sled to fit better within the coupler tube and be more efficient with space.

- [ ] Change OD to be under 5.5"
- [ ] Change position of Unified Board such that antenna fits better and doesn't hit potential screws if it goes through the switch band
- [ ] Rearrange components to be more space efficient
- [ ] Reduce wall thickness
- [ ] Potentially make it printable in one piece

varun-un, 2024-04-08:
closed with addition of ebay sled `v2`

Closed 2024-04-08.

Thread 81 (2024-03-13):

Modify Unified Board Form Factor

varun-un, 2024-03-13:
Create a new version of the Unified Board that is smaller in thickness such that it can fit into an L1 rocket that is 3" OD.

This may also involve changing other things about the Unified Board, as specified in Issue #82

Closed 2024-09-10.

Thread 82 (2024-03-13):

Enhance Unified Board

varun-un, 2024-03-13:
Make changes to the Unified Board to have it work better and be easier to debug.

- [ ] Add slots for multiple BNOs or BMPs for error/saturation correction
- [ ] Add more breakouts for GPIO pins and communication busses
- [ ] Modify antenna placement by moving RFM69HCW board
- [ ] Add modifiable LEDs to GPIO pins
- [ ] Add LEDs to data lines from IC chips to indicate transmissions or fixes
- [x] #81

Closed 2024-09-10.

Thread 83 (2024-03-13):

Create Teensy-like STM MCU board

varun-un, 2024-03-13:
Create an STM32 dev board that will allow us to test it and its subcircuits, by just plugging it into the Unified Board. It should be of a similar form factor as the Teensy, and have GPIO and communication bus pins in the same locations such that it can easily be plugged in.

This dev board should include auxiliary circuits to help do the following:

- [ ] Have a USB port to interface with a laptop for both Serial monitoring and programming (programmer circuit)
- [ ] Have an SD card reader for write to persistent memory storage on the SD card
- [ ] Be able to extend flash memory via a PSRAM or similar module, to write in-flight data to more quickly

DrewBrandt, 2024-03-13:
Do we need PSRAM if we simply give it enough actual ram to begin with? How do the prices vary?

dshi0322, 2024-04-21:
esd protection

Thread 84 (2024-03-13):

Add settling time for sensor bias correction

varun-un, 2024-03-13:
Determine if needed (via testing), and if it does, write/modify code such that for some period of time after board turn-on, instead of writing sensor readings to the SD Card, a running average is kept to determine sensor biases, which can then be subtracted out after to correct for error (mainly for the BMP if needed, but may be good for other sensors too).

varun-un, 2024-04-08:
Look at what airbrake does - recalibrate every 10 seconds or something else

Closed 2024-04-23.

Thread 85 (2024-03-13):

Self-positioning antenna system (optional)

varun-un, 2024-03-13:
We have 3 directional antennas that need to be pointed at the rocket, with an associated board and enclosure... It would be a lot easier if this were automatic 😺

Create a stand and CAD out an enclosure with some servos and associated code for this to happen based on receiving radio packets. Kinda like a full-on mini project.

Closed 2025-09-18.

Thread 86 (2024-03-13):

Look into Li-ion batteries instead of NiMH

varun-un, 2024-03-13:
Make sure it has enough amp hours and voltage, and make sure that it will still comply with everything. Look into potentially using an LVPD-style board with a voltage regulator to feed the Teensy 5V. If so, also ensure that the voltage regulator won't cause heat issues.

Closed 2024-09-10.

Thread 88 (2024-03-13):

Add formatting wrapper for fake data testing

varun-un, 2024-03-13:
In the [`StateTest`](https://github.com/Terrapin-Rocket-Team/SRAD_Avionics/tree/main/Spaceport/23-24/Code/Teensy-Based%20Avionics/src/StateTest) folder, there contains files for software-in-the-loop testing of the main board's code. When plugged into a Teensy, you can upload the main code (under the `StateTest` environment), and then run the `SendData.py` python script after to send fake data to the board. See [this comment](https://github.com/Terrapin-Rocket-Team/SRAD_Avionics/issues/54#issuecomment-1949630370) for more details.

This fake data sending process sends data from a past launch, stored in a CSV with certain columns and formatting. However, we want to be able to expand the testing data we use, by using CSVs and files from other subteams. This would require some wrapper or converter to ensure that their CSVs and formats align with our format, recording intervals, and columns, as that is what the Python file is expecting. Write this wrapper, and potentially integrate it as a preprocessor to the Python file to help support different data formats and sources.

DrewBrandt, 2024-03-14:
At the moment, if you want to run it with differently formatted data, you can change the column numbers in [`TestUtils.h`](https://github.com/Terrapin-Rocket-Team/SRAD_Avionics/blob/main/Spaceport/23-24/Code/Teensy-Based%20Avionics/src/StateTest/TestUtils.h). This is because at the moment, the python file simply sends the entire CSV row to the board and leaves it up to the board to decipher.

Also, in some branch somewhere I made a change that made it so that the board didnt care about the timing or spacing because it used the timing in the csv file. I cant find those changes now so maybe I undid them. Should be easy enough to simply add another column input and send it to State tho.

Something to consider is that during testing and sending the data to state manually, you have to actually edit the state class to comment out it's own time updating function. This should maybe be changed so that updateState accepts an optional int argument that, if a valid number, overwrites the state's own setTimeAbsolute(). Food for thought.

varun-un, 2024-10-09:
This would now be incorporated with the MMFS unit testing framework

Closed 2024-10-21.

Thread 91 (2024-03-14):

L1 Live Video Nosecone

varun-un, 2024-03-14:

jhauerst, 2024-04-05:
@varun-un I added the L1 nosecone CAD for Live Video to the Live Video folder. I'm closing this issue as completed, but feel free to reopen if there is more that needs to be done.

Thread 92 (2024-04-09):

Redesign EBay Sled

varun-un, 2024-04-09:
Redesign the EBay sled to address the following issues:

- [ ] Make screw terminals more reachable
- [ ] Make SD card more accessible
- [ ] Add clearance to LVPD and unified board to allow for Li-Ion batteries to be removed
- [ ] Ensure all screws for the LVPD are accessible via a screwdriver
- [ ] Mount the Raspberry Pi with 4 holes
- [ ] Redesign such that removing one board doesn't need to remove others

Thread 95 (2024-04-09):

Fix State code

varun-un, 2024-04-09:
Fix the Unified Board code to work

- [ ] Fix stage detection
- [ ] Fix baro velocity

varun-un, 2024-04-15:
Issue with velocity could be implicit unsigned data types - need to test with board

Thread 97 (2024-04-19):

Fast teensy interrupt

varun-un, 2024-04-19:
Enable Serial to SPI communication of at least 300kBits/sec with a running buffer to enable live video transmissions.

varun-un, 2024-04-22:
implementation involved with live video - #69

jhauerst, 2024-08-22:
@varun-un Should this be closed now that #69 is closed?

Closed 2024-08-22.

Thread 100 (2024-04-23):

Various GPS fixes

DrewBrandt, 2024-04-23:
- [ ] Fix GPS Heading value not being properly reported
- [ ] Fix Time of Day (ToD) not working
- [ ] Investigate accuracy issues in the Z axis (Altitude) as X and Y appear to be about 5x as accurate.
- [ ] Determine if there are any other issues with how the GPS reports its data in the flight log.

DrewBrandt, 2024-06-23:
This issue needs to be moved to MMFS unless we move the hardware implementation back to here. I am firmly of the belief that packaging specific, tested hardware implementations with MMFS makes everything easier for everyone.

varun-un, 2024-09-10:
Though MMFS related, these issues could be MAX-M10S specific, and so a potential design choice could be having superclasses and stuff in MMFS but subteams have ownership over sensor-specific code - should flesh out though

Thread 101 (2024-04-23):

Prepare for integration with MMFS repo

DrewBrandt, 2024-04-23:
Michael wants Payload, Avionics, and Airbrake to begin working from the same base code for next year to prevent redundant development time. As part of that, State, the sensors, and some of the libraries will need to be implemented in a more portable way. This is a low prio issue that may not be done until summer.

DrewBrandt, 2024-06-23:
This branch is ready for testing. MMFS repo is at https://github.com/Terrapin-Rocket-Team/Multi-Mission-Flight-Software

The Kalman Filter repo is at https://github.com/Terrapin-Rocket-Team/Kalman-Filter

Closed 2024-09-23.

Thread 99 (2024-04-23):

Fix various BNO issues

DrewBrandt, 2024-04-23:
- [x] Set BNO to 16G max mode
- [ ] Investigate BNO Magnetometer issues
- [ ] Investigate possible issue with X Accel always reading ~0 m/s/s
- [ ] Investigate occasional I2C bus issues
- [ ] Restore previous calibration data via SD card

This is all currently implemented/being tested on Branch `After-Launch-Code2`.

DrewBrandt, 2024-05-30:
I2C Bus issues: https://forums.adafruit.com/viewtopic.php?p=889280#p889280

Perhaps the issue mentioned here. further investigation needed.

DrewBrandt, 2024-05-30:
Calibration: Per [this page](https://learn.adafruit.com/adafruit-bno055-absolute-orientation-sensor/device-calibration), BNO does not store calibration data between power cycles.

The dev branch for these issues will implement a new environment that allows someone to upload code to run the calibrartion steps and store them to the SD card. These will be in a folder called BNO_calib and have similarly incremented files to the log and lfight data, where it always tries to use the latest number.

If calib data is somehow determined by the calib process to be invalid, it won't store the data in a new file.

DrewBrandt, 2024-06-23:
Closed because we are finding a new IMU (maybe just using the Blue Raven)

Closed 2024-06-23.

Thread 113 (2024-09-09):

Design power handling board

jhauerst, 2024-09-09:
As we transition to working with lower level hardware, it would be good for us to have designs for power delivery circuitry to supply the correct voltages for various sensors and other ICs. To this end, we should design a board that can ideally take any input voltage from the battery and produce the output voltages we need. While microcontroller boards like the Teensy often have some of this circuitry built in, it would be good to have a separate power delivery system that does not rely on these boards.

Tasks:
- [ ] We usually use 5V and 3.3V, so power converter(s) that produce these voltages need to be selected (needs to have a high max sustained current draw >3A). We can also add other voltages as needed (not sure if Payload or Airbrake might want other voltages).
- [ ] Design a PCB that integrates the required circuits for the power converter(s)
- [ ] The board should have a battery VIN and (multiple) 3.3V and 5V out, plus grounds

Closed 2025-02-18.

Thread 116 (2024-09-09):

Investigate Signal Distortion and Attenuation

LShapir0, 2024-09-09:
In order to support high fidelity in-flight telemetry and live video, our radio systems have to be reliable and precise. Antenna design is a significant (sometimes the most important) factor in the quality of a signal. Our antenna systems have to consider the following items:

A) The rocket will be traveling at super sonic speeds in the y-axis
B) The rocket will be rotating about the y-axis at a significant rate
C) The rocket will hit apogee at 30,000 ft

Factors such as [path loss](https://en.wikipedia.org/wiki/Free-space_path_loss), [polarization loss ](https://en.wikipedia.org/wiki/Polarization_(waves))  and the [Doppler effect](https://en.wikipedia.org/wiki/Doppler_effect#Satellites) will need to be investigated. A circularly polarized antenna will in theory reduce polarization loss.

Tasks:

- [x] Model and qualify Doppler effect (#122)
- [x] Design and verify a circularly polarized antenna (with prototyping)
- [x] Design breakout PCBs for patch antennas for VSWR, SWR, and efficiency parameters
- [x] Work around the physical constraints of the competition rocket (carbon fiber tube, limited space, limited power)

LShapir0, 2024-09-16:
Doppler affect is also being investigated in issue #122 .

Closed 2025-02-07.

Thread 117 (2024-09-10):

Research Batteries

varun-un, 2024-09-10:
In the past we used NiMH 4.8V batteries, but these are bulky as well as not being as "efficient" as other batteries. Part of this task is to research the pros and cons of different battery types and choosing one for us to use. They should be able to provide at least 3.3V (dependent on #113 specs), as well as hold good amounts of power (for example, 2000 mAh) to give us lasting battery life. Look into:

- [ ] NiMH batteries
- [ ]  Li-Ion batteries
- [ ] LiPo batteries (though Spaceport rules may discourage this)

With this, you should create a power budget for our sensors to find a battery that can supply that for a long enough duration. Consider the power draw, current draw, and voltage requirements for the following components:
- [ ] Teensy 4.1 and/or STM32
- [ ] DPS310
- [ ] BMI088
- [ ] LIS3MDL
- [ ] MS5611

Closed 2024-10-09.

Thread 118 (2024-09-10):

Create Simple Teensy MCU Board

varun-un, 2024-09-10:
Just a simple board with a few breakout pins for communication protocols like I2C and easily placed JST connections to the sensor board over I2C. Only real component on it is the header pins for the Teensy 4.1.

Could be useful to add external breakout pins for SPI/Serial for COTS sensors like Blue Raven or VectorNav IMU

Closed 2024-09-25.

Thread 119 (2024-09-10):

Enhance Sensor Board for v1.1

varun-un, 2024-09-10:
Look to potentially add the following to the sensor board:

- [ ] I2C connections for COTS sensors
- [ ] Add LEDs to data lines from IC chips to indicate transmissions or fixes
- [ ] Fix issues with v1.0 from testing

DrewBrandt, 2024-09-11:
I think there might be an issue with the LEDs as unlinke SPI where each IC has its own CS pin, I2C has a unified bus, so we would only know about comms on the bus, not comms between specific ICs

Closed 2024-10-23.

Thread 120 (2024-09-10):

Charge Deployment Test Board Software

varun-un, 2024-09-10:
Overlaps with #17, as it's dependent on the testing plans, but an independent Charge Deployment codebase will be needed. A simpler set of files will help reduce charge deployment error, so that needs to be built out. Should be capable of doing the bare minimum, yet enough, to perform what is effectively a charge deployment test on an L1 (though it'll be conducted on the ground).

Could use MMFS with a very much simplified State.

DrewBrandt, 2025-01-07:
Thinking a bit about safety, I propose a few things: first is a hard timer lockout from power on before launch detection capabilities. We already basically have this with MMFS because it takes 10-15 seconds to boot up. But something so that you cant turn it on and have it immediately explode, no matter what.

The other thing I was thinking was a loud buzzer that goes off for some amount of time (like 1 second) before the charge fires. We could use apogee prediction via acceleration to estimate when the charge should deploy, and for at least one second before that happens, sound a buzzer. This way, if it's on the ground, it would grab people's attention and they could either turn it off or move their hands away from it should they hear it beep. It should be louder than our current buzzer and a different pitch, if possible. Perhaps instead of a constant tone it's a very rapid beeping.

Closed 2025-09-18.

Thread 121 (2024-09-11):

Validate KF Coefficients

varun-un, 2024-09-11:
Using Matlab/Python, with a mix of real data and Gaussian-generated noisy data, assess the current KF model's noise and coefficient matrices for their accuracy. Attempt modifications if needed.

Closed 2024-10-21.

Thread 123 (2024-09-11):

Research supersonic effects

varun-un, 2024-09-11:
As the rocket goes transonic and potentially supersonic, we may experience shockwave and high dynamic pressure effects that come with the supersonic regime. This task is to research the potential, if any, effects this may have on our sensors and systems. This may include, but not be limited to:

- [ ] How the barometer is affected when entering and exiting local supersonic flow, and how a potential shockwave may disrupt its measurements
- [ ] Does the MAX-M10S hit CoComs limits at these speeds?

Closed 2025-02-10.

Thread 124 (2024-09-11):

Launch Data Analysis

varun-un, 2024-09-11:
This task is has two parts, both of which are optional but could be nice-to-haves, so long as the overhead of it isn't a lot and doesn't mean we're overengineering it.

- [ ] Find some easy way to deal with data and tag it.
   - Currently, they're stored as CSVs in the Google Drive, and if this is best, leave it be
   - There is potential to find ways to tag and label datasets (which subsystem, which sensors, which launch altitude, what launch platform (L1, L2, SAC, etc), weather conditions, etc).
   - If useful and doesn't introduce overhead to data management, implementing a more structured database that makes it easier to query data
- [ ] Run data analyses on these launch data sets to analyze for trends
   - things like sensor fidelity, differin data by subsystem (and the corrections for this), correlations/differences between launch data and simulated predictions, etc.

varun-un, 2024-09-17:
https://docs.google.com/spreadsheets/d/1IjHTOIJnAa9HkHqhLOqeBs86qzPdmZajJZ6ffPG4jM8/edit?usp=sharing

Closed 2024-10-21.

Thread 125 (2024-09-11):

Research Non-linear Kalman Filters

varun-un, 2024-09-11:
Research some non-linear Kalman Filters and see if they could have potential to help improve our filter's fidelity as well as potentially help increase our model state space. This would be things like EKFs, etc.

varun-un, 2024-10-17:
Plan:

Look at LKF -> EKF -> AKF for mach dip -> AKF for gyro drift -> EKF + AKF

Closed 2024-10-17.

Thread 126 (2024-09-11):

Dynamic Kalman Filters / Optimization

varun-un, 2024-09-11:
There is some optimization that can be done on our KFs, such as our parameter and coefficient specifications for things like sensor noise, so there is a potential to implement automated/learning optimization models to minimize our variances and errors to find better coefficients, if they exist.

This task is to research and potentially develop some of these methods, which may be anything from simple gradient descent optimization on our LKF to full on Adaptive KFs. This is ambitious and may be unnecessary, so if we are to implement something like this, there needs to be justification/proof of benefit

varun-un, 2024-09-11:
Useful paper: https://www.sciencedirect.com/science/article/pii/S1367578823000731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

varun-un, 2024-10-28:
Look at Bayesian Optimization: https://docs.google.com/presentation/d/1CxUI5u8NG1F5PyMZDT-WGybDiwL74pYkN6WoqNeT1R8/edit?usp=sharing

Slide 28-29 in PDR

Closed 2025-09-18.

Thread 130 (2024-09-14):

Create Si4463 Integration Testing Board

jhauerst, 2024-09-14:
Due to the form factor of the COTS breakout for the Si4463 that was ordered, an additional PCB will be required to connect the breakout to a Teensy and antenna. This board should provide connections from the all available pins on the breakout to the corresponding Teensy pins, and contain a 50 ohm impedance matched trace to connect to a side mounted SMA. Ideally this board will also be able to fit in an L1 for testing, so its shortest dimension should be <2.5 inches, including the antenna.

This issue is high priority since the boards need to arrive, be soldered, and get tested before the October launch.

Closed 2024-09-24.

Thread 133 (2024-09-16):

Si4463 Low Power module design

jhauerst, 2024-09-16:
Even though we will be getting COTS breakouts for the Si4463, it is possible there are some issues with them that would still require us to build our own breakouts. The first step in this is creating a breakout board that just integrates the Si4463 chip, and all required filter and matching circuits, into a breakout board. This board would have insufficient transmit power for the range we need, but it will help us get familiar with designing PCBs with RF circuits, and give us a starting point for the high power module.

The board should include the following components:
- The Si4463
- As per the Si4463 datasheet, a matching circuit and a low pass (LP) filter
- An SMA antenna connector
- Headers that breakout all available GPIO, SPI, or other interface pins on the Si4463
- Optional: LEDs to indicate radio status

The Si4463 [datasheet](https://www.silabs.com/documents/public/data-sheets/Si4463-61-60-C.pdf) and relevant application notes should be used as a guide when designing this board.

Closed 2024-12-23.

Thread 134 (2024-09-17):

Remote MCU Server

varun-un, 2024-09-17:
One of the difficulties of embedded systems programming and testing is that a lot of it can't be done on your laptop, and needs a Teensy or other MCU to do so. This mini project would be to create the PCB and hardware for a Teensy (that also has access to all the sensors we use, and maybe a couple extra) that could connect to the internet and setup as a remote server that people could realistically either SSH into or run code to test on remotely. This would require some hardware development as well as relatively low-level software development and network skills. This remote MCU server would also help with CI testing and future code development.

This is a low-priority fun little side project.

Closed 2025-07-18.

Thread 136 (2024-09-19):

Design Interface with Blue Raven

varun-un, 2024-09-19:
- [x] Research communication with Blue Raven system whether it be Serial or some protocol
- [x] Define physical interface (are we just going to take a USB cord and strip out the wires, etc)
- [ ] Add physical connections into either Sensor Board or MCU Board

Separate task for software side

DrewBrandt, 2025-03-04:
Airbrake has this implementation, and we have no plans to use it, so I'm closing this.

Closed 2025-03-04.

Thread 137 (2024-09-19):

Research Visual Odometry for IMUs

varun-un, 2024-09-19:
Some robots and even rockets use visual odometry to either augment or even replace their gyroscope systems for orientation determination, and potentially even position calculations. Since Avionics has a camera anyways, just research what a system using this camera feed for visual odometry would look like, as well as if it's even possible given our use case and camera views.

DrewBrandt, 2024-09-19:
Can you add more context about which camera we use, what its resolution is, what device we use to get video out of it, if there are space or power limitations, etc?

varun-un, 2024-09-19:
If we are to use the same hardware as last year (which is presumed), it's an [innomaker 5MP Raspberry Pi Camera](https://www.amazon.com/Inno-Maker-Camera-Module-OV5647-Raspberry/dp/B07G9VLPZH), and is capable in theory of 1080p and probably running at 30 fps. The idea is that we could split off the same camera feed that's going to the encoder and live video system and use it for this.

The big limitations come in the actual processing of it however, as I'm not sure how much spare processing power the RPi will have for this as well as if we have to stick another Raspberry Pi it'll become too much space and power draw. Realistically, this task would be a side project as an experimental thing, as making it operational would be hard.

Especially if you're trying to use something existing like [NVIDIA Isaac](https://github.com/NVIDIA-ISAAC-ROS/isaac_ros_visual_slam), the processing requirements far exceed what we have. So part of this would be to even determine the feasibility of this on a model rocket in general

Closed 2025-07-18.

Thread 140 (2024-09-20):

Design Inter-rocket Bluetooth System

varun-un, 2024-09-20:
One potential for getting other subsystems (Airbrake, Payload) data to our radio so that they can get transmitted to the ground is through Bluetooth connections. Research and pick a simple, low-power bluetooth model that can interface with an MCU board easily and transmit data between them.

- [ ] Pick bluetooth module
- [ ] Modify PCB to connect to Bluetooth module
- [ ] Extend `Radio` class and write software to handle communication

DrewBrandt, 2025-01-07:
Thinking more abut this:

We want to gather radio data to send to the ground, but it would also be great if they could send data to a phone app while on the ground with more complete system information than standard telemetry packets would allow. This would allow us to know our system's status as well as possible prior to launch.

I did a bit of basic research into this and it looks like there a re few modules that would work, including ones by ublox (who makes our GPS module). They reportedly have a range of 1400 meters and can well handle the rate of data. They are also their own self contained micro controller that we can program to run code if we wish. I'm not saying we go with these, but I am saying there are affordable options out there that definitely fit our needs.

varun-un, 2025-01-07:
Yeah I think any bluetooth module with enough range for low power would work. would you wanna make the bluetooth to phone thing a separate issue?

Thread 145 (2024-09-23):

BMI088 (Accelerometer & Gyroscope) Implementation

DrewBrandt, 2024-09-23:
Write code interact with a BMI088 over I2C. Using an external library is fine for this (See MMFS's dependency on SparkFun's GNSS v3 library and our MAX-M10s's implementation of it as an example).

The sensor will need an `int()` method to establish communication and set up configuration, and a `read()` that reads the registers and updates the appropriate variables.

These classes should be pretty simple and most of the work will come in either determining what to write to the registers or which library to use to write to the registers for us.

Closed 2024-10-04.

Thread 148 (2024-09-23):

LIS3MDL (Magnetometer) Implementation

DrewBrandt, 2024-09-23:
Write code interact with an LIS3MDL over I2C. Using an external library is fine for this (See MMFS's dependency on SparkFun's GNSS v3 library and our MAX-M10s's implementation of it as an example).

The sensor will need an int() method to establish communication and set up configuration, and a read() that reads the registers and updates the appropriate variables.

These classes should be pretty simple and most of the work will come in either determining what to write to the registers or which library to use to write to the registers for us.

Closed 2024-10-23.

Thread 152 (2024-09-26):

Smallest Flight Computer Ever

varun-un, 2024-09-26:
I think it would be a funny project to create the smallest flight computer possible. I've found a couple extremely compact package sensors that we could use, though ultimately this would be a small side project for fun that is low priority. It could serve as an example though to demonstrate and experiment with the extensibility of MMFS (if we're reaching for a justification).

Here are some ideas for possible sensors/chips to use:
- GSD4E-9333-TR (GPS chip)
- MIA-M10 (GPS chip)
- L70RE-M37 (GPS chip)
- W3011 (GPS antenna)
- BM1390GLV (Barometer)
- BMA580 (Accelerometer)
- STM32C011F6U6TR (MCU)
- ESP32-C3 (MCU & Bluetooth)
- CR1216 (Battery)
- SR512SW (Battery)

Things like data storage (probably using an EEPROM or EE PLD) and how to connect it to anything (like a computer) need to be figured out, as well as how it would even be assembled.

Closed 2024-12-21.

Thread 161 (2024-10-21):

GPS Patch Antenna Breakout

varun-un, 2024-10-21:
Make a breakout for the GPS patch antenna. This will be a board with the following:

- [SGGP.12.4.A.02](https://www.mouser.com/ProductDetail/Taoglas/SGGP.12.4.A.02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) GPS/GLONASS/GALILEO 12*12*4mm SMD Mount Patch
- SMA Connector (Side Mount or horizontal Through Hole)
- Ground Plane

Try to center the patch on the ground plane

Closed 2024-10-28.

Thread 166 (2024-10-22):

Model and print an eBay sled for an L1 nosecone

DrewBrandt, 2024-10-22:
We can either use Joseph's existing system or, if the teensy and sensor board have different needs, make a different one.

DrewBrandt, 2024-12-10:
Changes required:

- [ ] Holes need to be slightly wider
- [ ] Add threads for nose cone top? Maybe

Closed 2025-01-07.

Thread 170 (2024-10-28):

Improve Controller Board

varun-un, 2024-10-28:
- Add 5 pin connector for USB in the middle of Teensy
- Improve routing
- Make size smaller
- Optimize breakouts
   - 2 I2C
   - 2 SPI
   - 2 Serial
   - extra LED
   - set of 3 pins (2 GPIO, 1 GND)

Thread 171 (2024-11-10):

Fully featured Si4463 code

jhauerst, 2024-11-10:
Develop the fully featured radio code, building off of the code started in #112. This includes full working transmission of live video on the software side, support for messages longer than the FIFO length, and generally resolving any issues left over from #112.

Tasks (in recommended order):

- [x] Figure out which, if any, registers from the ```setRegisters()``` function need to be modified based on other settings (e.g. transmit frequency, frequency deviation, bitrate)
- [x] Enable AFC, and test that it works and successfully compensates for Doppler shift
- [x] Remove any blocking conditions from the RX and TX function chains, or develop non-blocking versions
- [x] Add functionality to enable message lengths longer than the FIFO length
- [ ] Test live video transmission working without ECC
- [ ] Test live video transmission working with ECC
- [x] Ensure compatibility with low power and high power modules

Closed 2025-09-18.

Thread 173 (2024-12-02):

Create comp rocket sled

varun-un, 2024-12-02:

DrewBrandt, 2024-12-10:
Some refinements are needed:

- [ ] Allow Radio Teensy to be accessed by USB while mounted
- [ ] Zip Tie holes for FC battery
- [ ] Less platform area where not needed so that Sunjum can see down into the COTS section
- [ ] Slight fillet on the area where the spacers meet the platform to make that section a bit stronger
- [ ] Allow Radio antenna to be straightened while board is mounted (i.e. cut out the hole so the antenna can fold in and out of it)
- [ ] .
- [ ] Anything else?

Closed 2024-12-21.

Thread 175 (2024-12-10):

GPS and radio transmitter interfere with each other

DrewBrandt, 2024-12-10:
Find the cause and fix pls

DrewBrandt, 2025-01-11:
Notes: We discovered we were using the wrong GPS module, but were still unable to get a separate Controller board and radio board working.

We solved the issue by getting rid of the Radio's middle-man teeny and flying our FC code on the radio board.

Closed 2025-01-11.

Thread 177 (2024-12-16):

Make compact Controller Board

varun-un, 2024-12-16:
Make a second version of the controller board, `v2.0`, that is much smaller by copying it to a new folder and editing the new version. It would only have the battery terminal, screw switch terminal, buzzer, LEDs (if useful), 1 I2C and 1 Serial/UART bus needed. To shrink it, you can make the teensy be one side and the headers and connectors be on the other.

Ideally, the width of this board would have to be <1.5in, and length wise should be as short as possible, so about the same length as the Teensy itself (just enough for the teensy to fit).

Closed 2025-01-06.

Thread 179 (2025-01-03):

Flight computer code crashes after running for a long time

jhauerst, 2025-01-03:
I ran into a crash of the flight computer while testing it with the radios (though the source of the crash is probably unrelated). I was testing with the code on the main branch before all Drew's camera code was added with a couple small modifications to the main file for radio stuff. I've copied the crash report below.

```
CrashReport:
  A problem occurred at (system time) 1:27:27
  Code was executing from address 0xC9B6
  CFSR: 82
        (DACCVIOL) Data Access Violation
        (MMARVALID) Accessed Address: 0x0 (nullptr)
          Check code at 0xC9B6 - very likely a bug!
          Run "addr2line -e mysketch.ino.elf 0xC9B6" for filename & line number.
  Temperature inside the chip was 49.43 °C
  Startup CPU clock speed is 600MHz
  Reboot was caused by auto reboot after fault or bad interrupt detected
```

I ran ```addr2line``` and got the following:
```
SRAD_Avionics\Spaceport\Code\Teensy-Based-Avionics/.pio\libdeps\teensy41\TRT-MMFS\src\Math/Matrix.cpp:149 (discriminator 3)
```
which is
```cpp
Matrix Matrix::add(Matrix other)
{
    if (this->rows != other.rows || this->cols != other.cols)
    {
        //std::cerr << "Addition error: Dimensions do not match!" << std::endl;
    }

    double *result = new double[this->rows * this->cols];

    for (int i = 0; i < this->rows * this->cols; ++i)
    {
        result[i] = this->array[i] + other.array[i]; // <- line 149
    }

    return Matrix(this->rows, this->cols, result); // returns sum matrix
}
```

I had to recompile with the -g to get addr2line to work, and the line it gave seems reasonable to have caused the error. Also not sure whether this is an issue with MMFS or the flight computer code which is why I put it here. I was able to reproduce the error, but it takes a long time since it only occurred after the flight computer was running for probably close to an hour. Unfortunately I didn't have an SD card in the first time, and the second may have gotten corrupted so I don't know the exact time. @DrewBrandt @varun-un any thoughts?

jhauerst, 2025-01-03:
I was able to reproduce the issue twice. Unfortunately it did not occur at the same time during both runs. The last data point logged for the second run was at 2647 sec, and for the third run at 3329 sec.

DrewBrandt, 2025-01-07:
that's... a long time. But definitely an issue. I'll have a look too, hopefully we can figure it out before Saturday.

jhauerst, 2025-01-08:
Not completely sure, but I think the last time I tested it was using this one: 7de28a84c4762c104baf1321d8909e7ef9041b22

DrewBrandt, 2025-01-08:
moving to launch in feb since it takes a long time to occur and I can't reproduce it after > 2 hours

Closed 2025-05-09.

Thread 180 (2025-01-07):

Flight Computer Radio Commands

DrewBrandt, 2025-01-07:
The flight computer needs to be able to receive commands from the radio and act on them. This is an incomplete list of what we'd like to be able to do:

- [ ] Turn the video system on/off
- [ ] Start/Stop recording video
- [ ] Restart the Flight Computer
- [ ] Launch/unlaunch the rocket (i.e. putting `State` into Stage 1, not actually physically launching it. Useful if launch detection fails.)
- [ ] Query Value (i.e. if we want to know the status of some variable that we don't want to send in every telemetry packet) Which variables we can query would, of course, need to be predetermined.
- [ ] Radio Frequency Hop (change the radio module's frequency on command)
- [ ] Restart Airbrake (maybe)
- [ ] Actuate Airbrake (maybe)
- [ ] Restart Payload (maybe)

The pi is expected to communicate with the Teensy in one of two ways: UART or GPIO pins. This ticket sort of relies on this system being implemented and decided on.

The radio code to handle receiving these commands should not be handled by this ticket. The radio system should have an API for a command packet that this system can call on to receive commands.

There should be some sort of acknowledgement system. The way we currently think it should work is that the ground station waits to receive a telemetry packet and if it has a command queued up to send, it fires it off before the FC sends the next packet. In every packet there will be space reserved for an Ack bit, usually low but set high if the the FC just received and understood a command. We may want to have some kind of repeating system in the event of packet loss, but I think that will mostly come from the ground station side.

Finally, we will have a single JSON file that explicitly lists all commands, their syntax, arguments, descriptions, etc. and this will be parsed by both the FC and the GS to make sure they stay on the same page about which commands mean what and how they work. I think Joseph is currently working on a first draft of this file.

Closed 2025-09-18.

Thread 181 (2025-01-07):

Raspberry Pi Video Commands

DrewBrandt, 2025-01-07:
The video system should be able to take in at least two commands:

- [ ] Start/Stop video
- [ ] Turn system On/Off

The system will communicate over UART with the FC

Update:

The on/off will not be something we can control on the raspberry pi's side. We will need a switch somewhere that powers the pi on or off, so the only part the pi needs to worry about is the start/stop recording function.

We'd like it to acknowledge when it has completed a requested command, so the FC can log it.

I think since we only need this one command, doing it via two GPIO pins may be easier than using UART.

Basically, the FC sets one pin high, and when the rpi is done with whatever "pin was set high" should do, it sets the response pin high. vice versa for FC setting input pin low.

I might recommend using UART tx/rx pins on the pi for this though, so that if we later decide we need mroe commands and want to implement a full UART communication, it's just that much easier to switch the pins from being GPIO to being UART.

DrewBrandt, 2025-01-08:
```python
import RPi.GPIO as GPIO
import subprocess
import time

# Setup
CMD_PIN= 14  # GPIO pin number
RESP_PIN = 15 # response pin
GPIO.setmode(GPIO.BCM)
GPIO.setup(CMD_PIN, GPIO.IN, pull_up_down=GPIO.PUD_DOWN)
GPIO.setup(RESP_PIN, GPIO.OUT)

recording = False
process = None

def start_recording():
    global recording, process
    if not recording:
        print("Starting recording...")
        process = subprocess.Popen([
            "libcamera-vid",
            "-o", "video.mp4",
            "-t", "0",
            "-n",
            "--width", "1080",
            "--height", "720",
            "--hdr", "auto",
            "--framerate", "15"
        ])
        recording = True
        GPIO.output(RESP_PIN, GPIO.HIGH)

def stop_recording():
    global recording, process
    if recording and process:
        print("Stopping recording...")
        process.terminate()  # Gracefully terminate the process
        process.wait()       # Wait for the process to clean up
        process = None
        recording = False
        GPIO.output(RESP_PIN, GPIO.LOW)

try:
    # Start recording automatically on boot
    start_recording()

    while True:
        if GPIO.input(CMD_PIN) == GPIO.LOW:
            stop_recording()
        else:
            start_recording()
        time.sleep(0.1)  # Debounce and CPU usage control

except KeyboardInterrupt:
    print("Exiting...")
finally:
    GPIO.output(RESP_PIN, GPIO.LOW)
    GPIO.cleanup()
```

This is what I did for my L1 when I was testing my rotating camera. Obviously, we won't be using libcameravid, but the GPIO input and output can be seen here.

We are using Raspberry Pi 4B, so yu can look up pinout diagrams for them and choose pins that you feel work best.

Closed 2025-09-18.

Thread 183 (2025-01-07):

Assemble and Test PD board

DrewBrandt, 2025-01-07:
If you're interested in learning how to assemble the PCBs once we get them in, assign yourself to this and we'll let you know when this board arrives.

Closed 2025-03-04.

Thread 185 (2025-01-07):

Create fully-featured-but-still-small Teensy breakout board

DrewBrandt, 2025-01-07:
Should have connections for:

- [x] 2x i2c (different i2c busses) - Sensor board and one backup
- [x] 2x UART - Bluetooth and one backup
- [ ] 1x SPI (5 pins) - Radio
- [ ] 1x 2 pin power - Power
- [ ] 1x 2 pin Screw Switch - Power
- [ ] 1x UART with extra GPIO pin for raspberry pi power enable
- [ ] 1x 5 GPIO pin for camera control
- [ ] 1x 1 GPIO for PD board

~~Whether or not these supply power and have a ground connection is up to what we decide in slack.~~
- [ ] The bluetooth and sensor board (i.e. both i2c connections) should have 3.3v and ground power connections.
  - The order for the i2c pins is 3.3v -> SDA -> SCL -> GND. No other connectors have order requirements.
- [ ] The Radio and camera connectors should have 5v and ground connections.
- [ ] The PD board should have one ground pin with its GPIO pin.

Other requirements:

- [ ] 1x Buzzer
- [ ] 1x Power indicator LED (don't forget current limiting resistors, we've used 2k in the past)
- [ ] 1-3x GPIO LED (more is better if they fit)
- [ ] 4x 5.1k i2c pull-up resistors
- [ ] 4x mounting holes, M3 sized in a rectangular pattern preferred
- [ ] < 1.5" wide. No height constraint.

IMO if it's too hard to route the traces, just delete unused Teensy pin holes. We don't have solder all of them if they wont be used.

More specific requirements to come as the team decides more about power board.

Closed 2025-02-18.

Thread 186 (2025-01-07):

Miniaturize and remove the MS5611

DrewBrandt, 2025-01-07:
After testing, we discovered the MS5611 is considerably noisier than the DPS 310. It has failed us. Remove it.

Also see if there are ways to make the board even smaller. the 100nF caps can move down to 0603 size, as we have like 500 of those in stock.

Closed 2025-02-18.

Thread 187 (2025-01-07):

Bluetooth phone app

DrewBrandt, 2025-01-07:
Would be nice to have a phone app that can connect to the rocket's bluetooth module during launch operations to ensure that the system powers on properly. It could provide a nice UI to see Payload, Avionics, and Airbrake's systems and provide more detailed information than simple buzzers or standard telemetry packets. We could even potentially send commands back to the rocket to test sytems (like airbrake potentially testign flap actuation). It could read out battery charge levels or give us camera previews. Idk Bluetooth can do a lot and if we can get it working, we might as well use it to its full extent. I am happy to write the app, but I would write it in C# using Xamarin lol because that's the framework I know.

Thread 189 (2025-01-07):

Rotating Camera

DrewBrandt, 2025-01-07:
I've already started work on this, just putting an issue here to keep track of it.

Essentially, a very small mirror will stick out the side of the rocket, and we will rotate it to either look down at the booster, up at the parachute, or sideways towards the horizon. This will hopefully be able to replace our current live video setup. We would ideally be able to control the camera in-flight from the ground, or alternatively give it pre-set instructions to follow. this will let us see airbrake and chute deployments in action from the same camera. It also has an L1-sized compatible design.

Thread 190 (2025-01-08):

Implement a data save function if the rocket detects it's coming in balistic

DrewBrandt, 2025-01-08:
Basically just dump all current data on the PSRAM to the SD card if the state determines that the rocket is likely not under parachute. That way we save data from the ascent even if the rocket destroys itself on landing.

This should be relatively straight forward: In State.cpp, add a new method like `determineIfBalistic()`, and if stage >= drogue and z acceleration is < 1g (i.e. free-fall) (also could check barometer velocity for decreases consistent with free-fall), then log a warning or error, and call the `psram.setMode(ground)`.

We might want a way to backtrack this/continue full speed recording if we detect no drogue but do detect main. Main should deploy at about 1000 ft, and drogue shortly after apogee.

DrewBrandt, 2025-02-18:
superseded by decision to remove PSRAM storage from MMFS

Closed 2025-02-18.

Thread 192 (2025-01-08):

Add a "GPS lost fix" indicator

DrewBrandt, 2025-01-08:
We have a "got first fix" indicator, but if it loses fix, we wouldn't know. Maybe a beep sequence or make the GPIO LED we are using for fix indication blink again.

The current code is at the bottom of main in the loop. Just if has fix-> set on.

DrewBrandt, 2025-01-16:
I took care of this as a test/example in MMFS. See https://github.com/Terrapin-Rocket-Team/Multi-Mission-Flight-Software/pull/107

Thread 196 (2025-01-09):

Fiber optics for LEDs

DrewBrandt, 2025-01-09:
We want a way to be able to see the status LEDs from outside the rocket during launches. The way I thought that would be cool to do this is by using fiber optic strands to route the LED light to the shell of the rocket.

Another way we could achieve this effect is by making an LED breakout board that we simply mount to the inside of the rocket.

Closed 2025-07-18.

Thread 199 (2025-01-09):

SITL Testing

DrewBrandt, 2025-01-09:
We now have sensor mocks in MMFS that allow us to take in data from a file and process it as if it were real sensor data.

The next step is to design some kind of semi-automated system to test a number of our systems against that data:

- Kalman Filter
- Stage Detection
- IMU Orientation
- Telemetry
- Charge Deployment

We still need to figure out how this kind of system might work, but at the very least we need to start thinking about it.

Closed 2025-09-18.

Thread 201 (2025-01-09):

External Antennas

DrewBrandt, 2025-01-09:
Sunjum wants to make all the tubes out of Carbon Fiber. This is an issue for us because it blocks RF signals.

The idea here is to determine how feasible it is to externally mount patch or wire antennas either to the outside of the CF or embedded into the outer layer of it.

First thing to decide is whether it would work or be worth it, as routing the antennas inside may become an issue. We also need to make sure that we can still get as much of a signal as we would with our internal + fiberglass setup.

Next is to determine if we can embed them or if that's more trouble than it's worth. We'd need to connect with Aerostructures to help figure out if they can do it or not.

Closed 2025-09-18.

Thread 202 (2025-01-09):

Local Video Recording

DrewBrandt, 2025-01-09:
As well as transmitting live video, it would be nice to have a local recording in case something goes wrong with transmission.

jhauerst, 2025-07-18:
Closed with merging of #246

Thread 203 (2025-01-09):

Reed Solomon encoding and decoding

DrewBrandt, 2025-01-09:
This is error correction stuff for the radios. Ask Joseph for more info.

jhauerst, 2025-01-14:
Going to add a more detailed description:

In order to help prevent bit errors from affecting the live video stream, error correction codes are needed to correct bit errors on the receiving end. The algorithm currently planned on being used for this is Reed Solomon, which was chosen because it has good performance, can be used in MATLAB, and has an existing Arduino library that implements it. This issue involves testing performance the Arduino library for Reed Solomon error correction on a Teensy, and implementing encoding and decoding into the live video stream.

Tasks:
- [ ] Implement basic Reed Solomon encoding and decoding using the Arduino library
- [ ] Test encoding and decoding speed using a variety of block sizes and code rates, and record the results
- [ ] Perform tests with simulated bit errors
- [ ] Evaluate whether the measured performance is acceptable for live video, or select another algorithm
- [ ] If performance is acceptable integrate Reed Solomon into the live video processing chain

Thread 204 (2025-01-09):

Allow Pi to connect to serial console while connected via UART to Teensy

DrewBrandt, 2025-01-09:

jhauerst, 2025-01-14:
Adding description:

We often use the Raspberry Pi's Serial console to interface with it, but this requires a specific cable that needs to be plugged into the Pi's GPIO. Some of this GPIO will be used by the Live Video Multi-Function Board (MFB) to interface with the Pi, preventing access to the Pi's Serial console when the MFB is connected. This issue involves developing a solution to power and communicate with the Pi using the Serial console through the MFB. This could be as simple as breaking out the required pins to connect our usual cable to, or as complicated as using a UART to USB chip such as [this one](https://ftdichip.com/products/ft234xd/) to allow us to simply connect a regular USB cable.

Tasks:

- [ ] Develop a plan to communicate with the Pi using the MFB, weighing costs and benefits of each approach
- [ ] Select parts and develop or select a development board to test them
- [ ] Test that selected parts allow for communication with the Pi using the dev board and perform as expected
- [ ] Integrate the solution into the MFB

Notes:
The last task will need to wait until the MFB itself is made.

jhauerst, 2025-07-18:
Closed with merging #226 and #246

Closed 2025-07-18.

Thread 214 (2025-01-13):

PA test board

jhauerst, 2025-01-13:
The circuit for the radio PA looks like it could be a bit complicated, so it's a good idea for us to isolate that circuit to make testing easier. Mainly, we need to make sure that we have the right values for all the components in the bias circuit for the PA. Based on the datasheet, the best gain is achieved when the quiescent current of the PA is 455mA with no RF input, so we need to make sure the values we choose can produce that current. The PA also needs some DC blocking capacitors and matching circuits, so this board will allow us to make sure we have the right values for all those, without making a whole High Power module. Then we can simply use the same component values for the HP module.

Tasks:

- [ ] Transfer the circuit topology from the datasheet
- [ ] Find initial guess at correct component values for bias circuit
- [ ] Find values for matching circuits based on PA impedance in the 70cm band
- [ ] Develop a PCB layout to allow us to easily test PA performance
- [ ] Research ways of deactivating the PA (see Note 3 on page 4 of the datasheet)
- [ ] Optional: figure out a way to generate a sine wave at ~433Mhz to test the PA

Notes:
[PA datasheet](https://www.qorvo.com/products/d/da005671)

Closed 2025-02-13.

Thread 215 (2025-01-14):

Radio High Power module

jhauerst, 2025-01-14:
The High Power module improves upon the Low Power module with the addition of a 2W power amplifier on the TX side. This should improve our signal strength significantly by providing increased output power over the 100mW that the Si4463 can produce on its own. Otherwise this module should be about the same as the LP module, except that it should incorporate lessons learned from testing the LP module. This module may also require additional filtering to ensure proper suppression of spurious emissions.

Tasks:

- [ ] Integrate the PA circuit into the existing LP module TX circuit
- [ ] Develop a way of deactivating the PA to reduce current draw while the radio is not operating
- [ ] Figure out whether additional filtering is needed and add it if necessary
- [ ] Develop a new layout to include the PA

Notes:
Depends on testing of the LP module. Depends on completion of #214 and PA board testing.

Closed 2025-02-13.

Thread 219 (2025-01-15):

Add back Static Sensor Data

DrewBrandt, 2025-01-15:
Things that we want printed to the log file at launch. This was mostly removed because we weren't printing anything useful, but we can change that. At the very least, add the ability to easily do it.

DrewBrandt, 2025-02-22:
Closing because this is unnecessary

Closed 2025-02-22.

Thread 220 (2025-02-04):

Fix minor issues from 2/1 Launch

DrewBrandt, 2025-02-04:
- [x] 3 blank lines in log file after MMFS version??
- [x] "[ERROR] Radio Initialized" <- not an error (good first issue)
- [x] Apogee detected at 1km, which is incorrect (should have been ~7800 ft)
- [x] Rename "PreFlightData" to maybe "ground data" or "pre-post-flight data" or something as it includes data from before and after flight.
- [x] Add timestamps since launch to stage detection (like apogee detected - 21 sec into flight kind of thing) (good first issue)
- [x] remove logging DST and timezone logs from gps except first fix (good first issue)
- [x] fix setting date/time of file creation failing on gps fix

If you want to tackle any of these put a comment here about which one you want and I'll give you details. some of these are definitely not beginner friendly and some are. I may break this into separate issues but most of them are ~1 line fixes.

Oren-Freidlin, 2025-02-22:
I'd like to tackle the issue "Apogee detected at 1km"

DrewBrandt, 2025-02-22:
> I'd like to tackle the issue "Apogee detected at 1km"

This one may require a little bit of data analysis. here is the flight data from feburary: https://drive.google.com/drive/u/0/folders/1ternc7JzxbSb3lIY66OjbfUdQ8wpIMG9

In particular, you probably want the flight data csv and the log file. Use AvionicsState.cpp's determineStage to understand why it may have detected apogee early. My guess is that something happened that caused the barometer to report data where `current alt` < `prev alt`. This probably indicates that we need more robust stage detection. One solution is the Kalman Filter, but until that's working, we can implement some other kind of basic filtering or smoothing to prevent this kind of issue again.

I'd say step one is determining why it reported apogee so early, and the next step is deciding what to do about it.

Oren-Freidlin, 2025-02-23:
Issue found:

At around 2371.442 seconds (~7 seconds after start time), there is a small chunk of time where the position data collected is stagnant between two data samples, meaning the vertical velocity is zero. Since there is a condition in the code where if the vertical velocity is no greater than zero after 5 seconds in stage 2 to send to log the apogee was reached, this seemed to lead to the premature logging.

Me and Drew are still figuring out if this is a sampling issue or an issue with the DPS sensor (the data for the MS5611 seemed to record a more consistent velocity).

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

Azhanzz, 2025-02-27:
Id like to tackle "Add timestamps since launch to stage detection"

DrewBrandt, 2025-03-03:
Sorry I didn't respond, were you able to figure it out?

If not, part of the logging on stage detection in AvionicsState's `determineStage()` should log the timeSinceLaunch as part of the string. Idk if formattign it into "MM:SS" is better than just leaving it as seconds. Most likely the flight will be < ~2 mins, so we won't be seeing any crazy high numbers there. You can use the printf-style formatting provided by Logger to add the time.

See [this](https://drewbrandt.github.io/user-guide/utils/logger/#recording-data) if it helps.

Closed 2025-05-09.

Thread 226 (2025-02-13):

Live Video Multi-Function Board

jhauerst, 2025-02-13:
The Live Video Multi-Function Board (MFB) is essentially the "motherboard" for Live Video. It will provide connections between the Teensy, Raspberry Pi, radio, and power delivery systems. Ideally, it will be mounted to the Raspberry Pi as a "hat" style board, that is, a board mounted on the GPIO pins of the Raspberry Pi. This board must also be as compact as possible, since it will need to fit in the payload as well as the electronics bay.

## Tasks

- [x] Integrate the following components into a PCB schematic
  - 5V 3A power delivery
  - Teensy connection
  - High Power Module connection
  - Raspberry Pi GPIO connection
- [x] Design a PCB based on this schematic that fits the following requirements
  - Is (ideally) no larger than the Raspberry Pi footprint (excluding the radio SMA)
  - Can mount to the Raspberry Pi GPIO, with additional screws to secure the board in place
- [x] Select female pin header connectors that will allow the board to clear the Raspberry Pi heatsink
- [ ] Develop a reliable method to ensure the heatsink does not short the board
- [x] Ensure the final assembly of the Raspberry Pi + the MFB meets Payload's height requirements

## Notes
These [Adafruit pin header connectors](https://www.adafruit.com/product/1979) might work.
Contact Nathan or Cooper for Payload's height requirements.

Closed 2025-04-07.

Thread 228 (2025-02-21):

Motor Driver Code

DrewBrandt, 2025-02-21:
There is an STM32F103C8 that needs to take angle commands from the teensy over UART and then drive the stepper motor to that angle.

Here is the schematic showing the different pins that are used on the STM:

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

In particular, pins PA4,5,6,7 are the 4 motor coil energizing pins. Pins PA9 (tx) and PA10 (rx) are the UART Serial pins.

THe full schematic can be found here: https://github.com/DrewBrandt/SRAD-Avionics/tree/RotCam/Spaceport/PCBs/RotCam/Motor%20Driver

(that's in my fork of this repo, in the RotCam branch, in the `Spaceport/PCBs/RotCam/Motor Driver` folder.)

There is also a Hall Effect sensor that the system uses to determine its "home" position, plugged in to pin [something].

Here is where I did this camera rotating stuff before: https://github.com/DrewBrandt/SRAD-Avionics/tree/RotCam/Spaceport/Code/Teensy-Based-Avionics/src/RotCam

This starts by finding home, then finds out how many steps are in one rotation, then can be set to a specific angle.

The src/main.cpp file at that link indicates how to start it.

Basically for this, I want to send that angle over serial, and have the STM run the motor to that angle.

That's basically it.

Note: THe board I ordered forgot to include the Hall Effect Sensor's input pin. SO I'll have to probably solder a wire directly to the pads.... So I don't know which pin it will be yet. HE sensor is active low (when the pin goes low, there is a magnet in front of the sensor)

Closed 2025-07-18.

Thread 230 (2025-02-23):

Apogee detection issue (DPS sensor)

Oren-Freidlin, 2025-02-23:
At around 2371.442 seconds (~7 seconds after start time), there is a small chunk of time where the position data collected is stagnant between two data samples, meaning the vertical velocity is zero. Since there is a condition in the code where if the vertical velocity is no greater than zero after 5 seconds in stage 2 to send to log the apogee was reached, this seemed to lead to the premature logging.

Me and Drew are still figuring out if this is a sampling issue or an issue with the DPS sensor (the data for the MS5611 seemed to record a more consistent velocity).

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

Closed 2025-02-23.

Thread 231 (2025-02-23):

Apogee Detection Issue (DPS sensor)

Oren-Freidlin, 2025-02-23:
At around 2371.442 seconds (~7 seconds after start time), there is a small chunk of time where the position data collected is stagnant between two data samples, meaning the vertical velocity is zero. Since there is a condition in the code where if the vertical velocity is no greater than zero after 5 seconds in stage 2 to send to log the apogee was reached, this seemed to lead to the premature logging.

Me and Drew are still figuring out if this is a sampling issue or an issue with the DPS sensor (the data for the MS5611 seemed to record a more consistent velocity).

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

Closed 2025-05-08.

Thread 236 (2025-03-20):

ARCH Radio Code

jhauerst, 2025-03-20:
Alongside the radio code being developed in #171, Live Video/Avionics Rotating Camera (ARC) will require additional development of code interfacing with the radio code and the FEC code being developed in #203. This code will be run by the Teensy on the ARCH (ARC-Hat) board and will be used to interface between the Pi and the radio. It needs to be designed with special attention to performance and low latency. This means that, rather than the Teensy waiting to receive the entire message, it should be simultaneously reading from the Pi and passing those bytes along to the radio as they come in.

## Tasks
- [ ] Test dynamically loading the radio code internal buffer and the radio FIFO during transmission
- [ ] Develop a method of reading data from the Pi over I2C
- [ ] (Optional) Develop a method of reading data from an SD card for testing purposes
- [ ] Test fully integrated reading from the Pi and writing to the radio for acceptable performance
- [ ] Integrate Reed-Solomon FEC

Closed 2025-09-18.

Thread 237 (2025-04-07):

HPM v2

jhauerst, 2025-04-07:
## Description
Based on testing with the HPM v1, some changes will be needed to improve the ease of use of the module, specifically in regards to power. The buck converter circuit for 3.3V did not work with a 5V input, so I will be replaced with an LDO. Additionally, multiple modules have been damaged due to reverse or over voltage, so a protection circuit would also be good to implement. There are also some other minor improvements that can be made to try to improve transmit/receive signal quality.

## Tasks
- [x] Add overvoltage and reverse voltage protection
- [x] Add 3.3V LDO
- [x] Maybe switch to right angle JSTs (the vertical ones are kind of annoying and I think we're mostly out of them anyway)
- [x] Connect TCXO ground only to the correct radio IC ground pin (as per AN629)
- [x] Reduce number of LEDs
- [x] Ground vias around the board edge (as per AN629)
- [x] Look into other methods of improving isolation (including other recommendations from AN629)

Closed 2025-05-01.

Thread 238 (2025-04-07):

New COTS board

jhauerst, 2025-04-07:
## Description
As a backup to the SRAD radio boards, an improved COTS board should be developed to ensure we get telemetry and possibly video at IREC. This board should correct the existing issues with the COTS board that led to greatly increased noise, and be compatible with the interface that will be used for the HPM.

## Tasks
- [x] Correct noise issues with the COTS board design
- [x] Convert the COTS board form factor to be compatible with that of the HPM

Closed 2025-05-01.

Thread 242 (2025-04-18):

High-Range IMU PCB

varun-un, 2025-04-18:
Our current IMU (the BMI088) potentially saturated last launch at 24 Gs. This task includes the following, as part of our efforts to have a secondary backup IMU to validate the readings:

- [x] Find a cheap, small form factor IMU chip or board that has a high range (at least +/- 30 Gs or more)
- [ ] Create a small and compact breakout board PCB for this chip
- [ ] Make sure that it can connect to our controller board via I2C
- [ ] Extend the IMU superclass to create a class for this new IMU and write the code to interface with it within MMFS

dsrivas1, 2025-04-20:
Found the: KMX63-1055
MEMS Module, KMX63 Series, 3-Axis Accelerometer, 3-Axis Magnetometer, 1.7 V to 3.6 V, ± 64g, LGA-16 as a cheap IMU, will start working on it.

dsrivas1, 2025-04-21:
Using the ADXL375 instead

Closed 2025-05-13.

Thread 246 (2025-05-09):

ARC RPi Code Updates

jhauerst, 2025-05-09:
There are multiple updates that should be made to the Raspberry Pi code for IREC. This will be used to cover all these updates, both those listed in this issue and in other related issues.

## Tasks
- [ ] Consolidate Python scripts to streamline development and make it easier to switch between local and live video
- [ ] Update setup script to reflect new requirements and fix some issues
- [ ] Rename Live Video folder to ARC
- [ ] Add web interface for ARC
- [ ] Implements updates for and test code with the ARCH board
- [ ] Update ARC documentation

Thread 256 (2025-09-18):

Power Budget

LShapir0, 2025-09-18:
Our avionics system uses a wide variety of electronics that all require an external power source from a battery. In order to move forward with our new projects this year, we need to characterize the power requirement - how much power is needed to supply to all electronics. This analysis is called a power budget, and comes in the form of a list of every electronic component, max current draw, voltage, and electric power (I * V). Total draw is calculated by summing all respective currents.

After the power budget is created, batteries must be selected to meet the total power requirement. These batteries should be optimized around ampere-hour rating as well as size and weight.

Tasks:

- [ ] Create a complete list of all electronics and integrated circuits (ICs) that will be used in avionics this year
- [ ] Go on to the datasheet for each device to find max current draw and voltage. Power draw can then be calculated
- [ ] Format into a table
- [ ] Research battery chemistry that is optimized around ampere-hour (Ah) rating and weight
- [ ] Make recommendation for batteries to integrate

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

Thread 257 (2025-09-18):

Multiple Camera Angles

DrewBrandt, 2025-09-18:
Last year, as part of the live video competition, we attempted to live-stream a rotating camera view to the ground. This would have set us significantly apart from the other static, interior views offered by the teams. Our camera would look down the side of the rocket, getting a view of the booster and airbrake, and then rotate up to watch the parachutes deploy.

This year, we want to stay ahead of our competition and offer camera views that are only available on professional rockets. We want to design and implement a multi-angle system that allows us to choose from an array of cameras to show to the live-stream viewers.

Some camera angles we have in mind:
- Looking out of the rocket (boring, everyone does this)
- Looking down the rocket (look at boost & @ airbrake)
- Look up the rocket
- Look up at the rocket from the ground during launch
- Look out one of the parachute tubes
- Look down at the rocket from where the parachute connects to the shock cord
- Look out of airbrake to watch the flaps actuate

This solution can take really any form, but self-contained wireless modules would probably be best.

DrewBrandt, 2025-09-18:
Here is the solution I was going to explore:

Raspberry Pi Zero 2 W as the brain, with RpiCam 3 camera and a Li-ion battery.

These would stream their videos over wifi to a host Raspberry pi 5, at which point the live video system would transcode it to av1 and send it to the ground.

This means we could have a large number of independent camera systems dotted around the rocket, and pick and choose which ones we stream to the ground.

If someone picks this up, this doesn't have to be the solution, but th reason I chose it was for its cheap setup (~$50 per module), easy testing (it's just wifi), and small size (about half the size of a phone, probably).

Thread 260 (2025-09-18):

Automated Antenna Pointing

DrewBrandt, 2025-09-18:
We would like a system to automatically track the rocket and point our ground antennas in the right direction.

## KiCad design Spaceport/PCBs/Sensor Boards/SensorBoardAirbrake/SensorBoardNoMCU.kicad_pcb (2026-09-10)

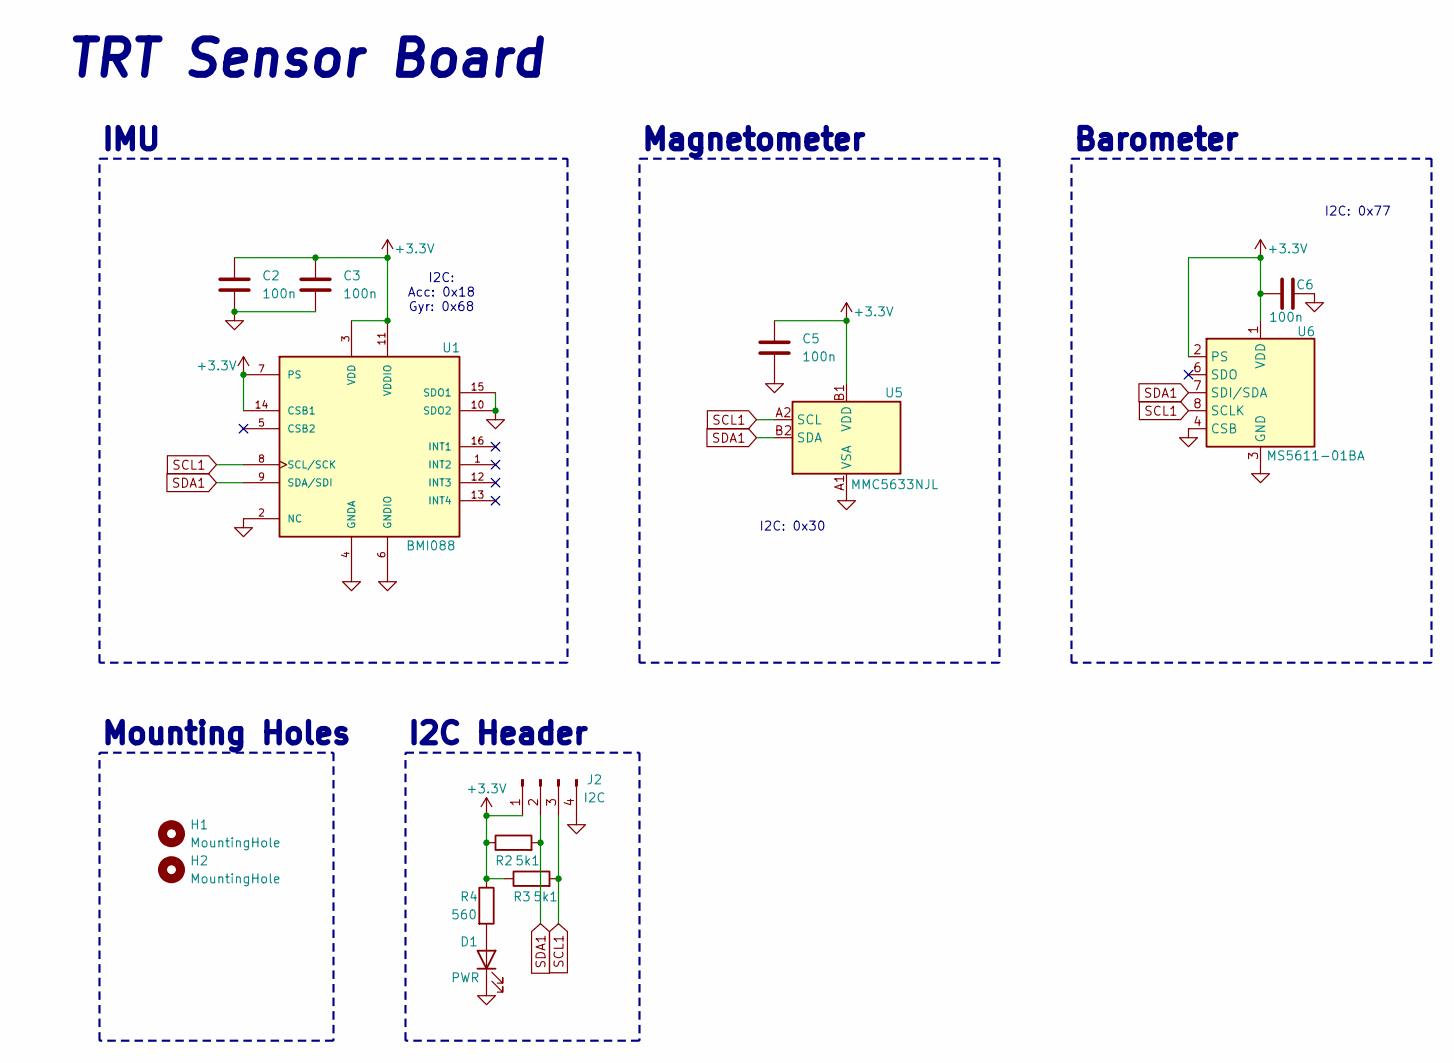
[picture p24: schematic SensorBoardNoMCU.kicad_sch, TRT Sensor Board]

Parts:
C2, C3, C5, C6: 100n; C_0603_1608Metric
D1: PWR; LED_0805_2012Metric
H1, H2: MountingHole; MountingHole_3.2mm_M3
J2: I2C; JST_XH_B4B-XH-A_1x04_P2.50mm_Vertical
R2, R3: 5k1; R_0603_1608Metric
R4: 560; R_0603_1608Metric
U1: BMI088; PQFN50P450X300X100-16N
U5: MMC5633NJL; WLP-4_0.86x0.86mm_P0.4mm
U6: MS5611-01BA; LGA-8_3x5mm_P1.25mm

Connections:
+3.3V: C2.1, C3.1, C5.1, C6.1, J2.1, R2.1, R3.1, R4.1, U1.3 (VDD), U1.7 (PS), U1.11 (VDDIO), U1.14 (CSB1), U5.B1 (VDD), U6.1 (VDD), U6.2 (PS)
GND: C2.2, C3.2, C5.2, C6.2, D1.1 (K), J2.4, U1.2 (NC), U1.4 (GNDA), U1.6 (GNDIO), U1.10 (SDO2), U1.15 (SDO1), U5.A1 (VSA), U6.3 (GND), U6.4 (CSB), U6.5 (CSB)
unnamed: D1.2 (A), R4.2
SCL1: J2.3, R3.2, U1.8 (SCL/SCK), U5.A2 (SCL), U6.8 (SCLK)
SDA1: J2.2, R2.2, U1.9 (SDA/SDI), U5.B2 (SDA), U6.7 (SDI/SDA)

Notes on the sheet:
IMU
TRT Sensor Board
I2C: Acc: 0x18 Gyr: 0x68
I2C: 0x30
Magnetometer
I2C Header
Mounting Holes
Barometer
I2C: 0x77

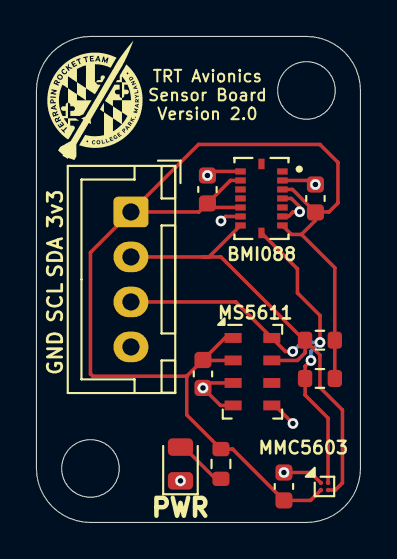
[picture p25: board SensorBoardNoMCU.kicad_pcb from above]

Board: 4 copper layers, 18.0 x 27.0 mm, 14 parts (0 on the bottom side), 5 nets.

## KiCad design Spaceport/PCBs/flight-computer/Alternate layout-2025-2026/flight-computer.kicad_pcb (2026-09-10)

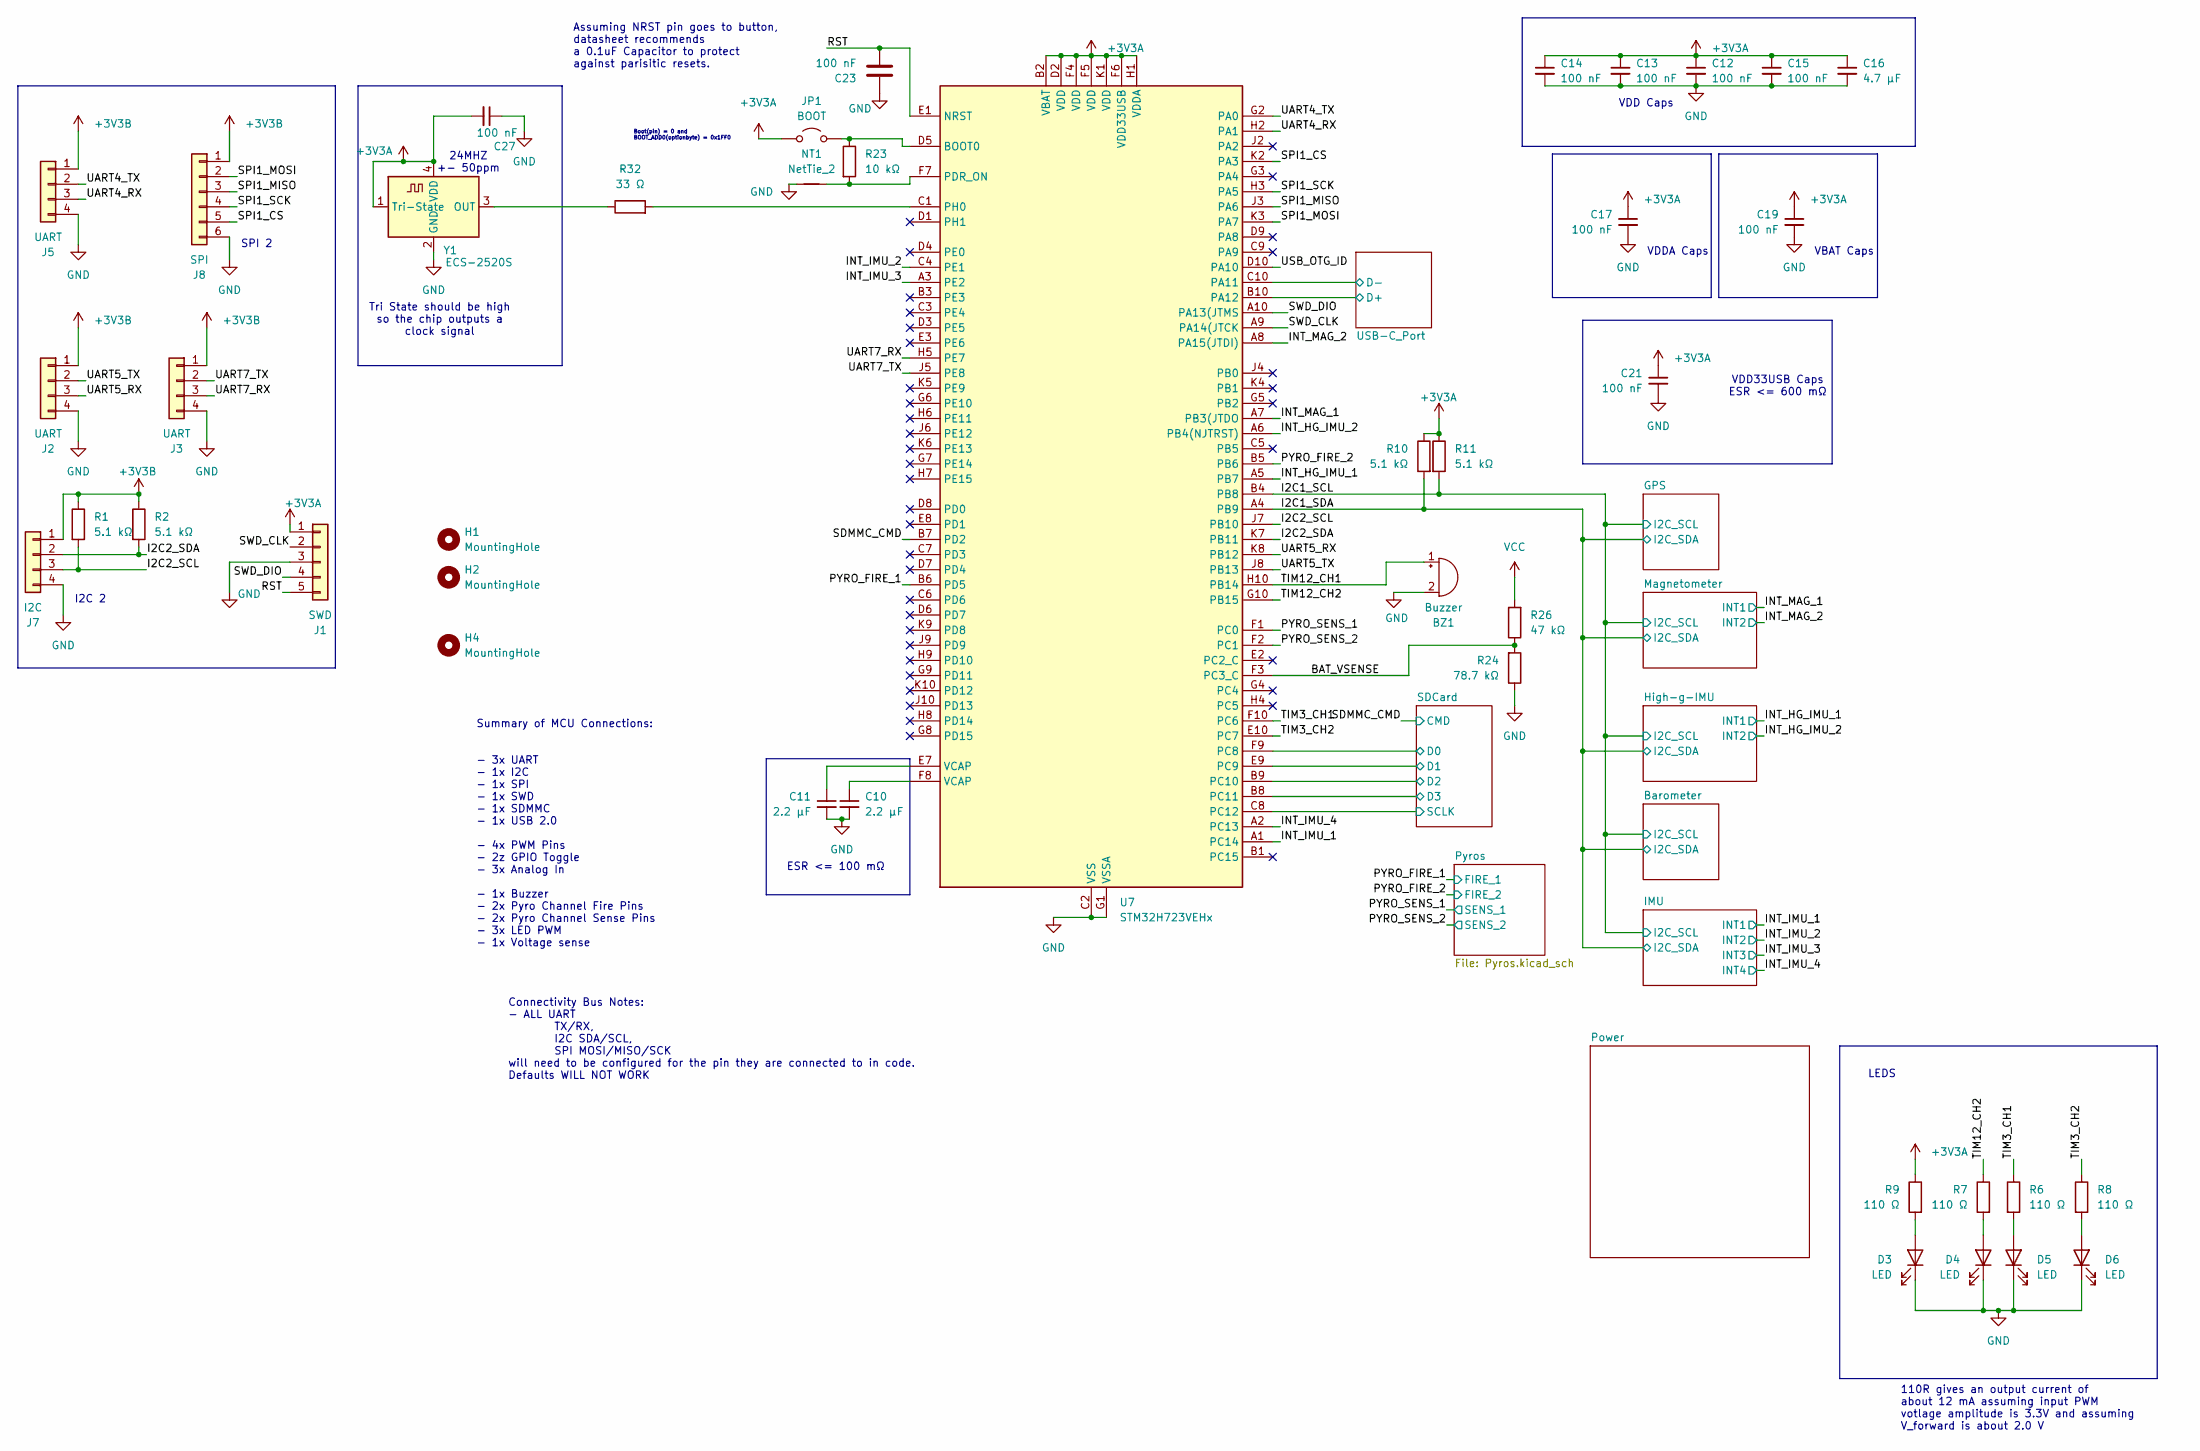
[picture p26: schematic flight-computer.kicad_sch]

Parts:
BZ1: Buzzer; Buzzer_Murata_PKMCS0909E
C10, C11: 2.2 µF; C_0603_1608Metric_Pad1.08x0.95mm_HandSolder
C12, C13, C14, C15, C17, C19, C21, C23, C27: 100 nF; C_0603_1608Metric_Pad1.08x0.95mm_HandSolder
C16: 4.7 µF; C_0603_1608Metric_Pad1.08x0.95mm_HandSolder
D3, D4, D5, D6: LED; LED_0805_2012Metric_Pad1.15x1.40mm_HandSolder
H1, H2, H4: MountingHole; MountingHole_3.2mm_M3_DIN965
J1: SWD; PinHeader_1x05_P2.54mm_Vertical
J2, J3, J5: UART; JST_XH_B4B-XH-A_1x04_P2.50mm_Vertical
J7: I2C; JST_XH_B4B-XH-A_1x04_P2.50mm_Vertical
J8: SPI; JST_XH_B6B-XH-A_1x06_P2.50mm_Vertical
JP1: BOOT; SolderJumper-2_P1.3mm_Open_RoundedPad1.0x1.5mm
NT1: NetTie_2; NetTie-2_SMD_Pad0.5mm
R1, R2, R10, R11: 5.1 kΩ; R_0603_1608Metric_Pad0.98x0.95mm_HandSolder
R6, R7, R8, R9: 110 Ω; R_0603_1608Metric_Pad0.98x0.95mm_HandSolder
R23: 10 kΩ; R_0603_1608Metric_Pad0.98x0.95mm_HandSolder
R24: 78.7 kΩ; R_0603_1608Metric_Pad0.98x0.95mm_HandSolder
R26: 47 kΩ; R_0603_1608Metric_Pad0.98x0.95mm_HandSolder
R32: 33 Ω; R_0603_1608Metric_Pad0.98x0.95mm_HandSolder
U7: STM32H723VEHx; TFBGA-100_8x8mm_Layout10x10_P0.8mm
Y1: ECS-2520S; Oscillator_SMD_ECS_2520MV-xxx-xx-4Pin_2.5x2.0mm

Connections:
+3V3A: C12.1, C13.1, C14.1, C15.1, C16.1, C17.1, C19.1, C21.1, C27.2, J1.1, JP1.1 (A), R9.1, R10.1, R11.1, U7.B2 (VBAT), U7.D2 (VDD), U7.F4 (VDD), U7.F5 (VDD), U7.F6 (VDD33USB), U7.H1 (VDDA), U7.K1 (VDD), Y1.1 (Tri-State), Y1.4 (VDD); also elsewhere on the board
+3V3B: J2.1, J3.1, J5.1, J7.1, J8.1, R1.1, R2.1; also elsewhere on the board
/BAT_VSENSE: R24.2, R26.1, U7.F3 (PC3_C)
/I2C1_SCL: R11.2, U7.B4 (PB8); also elsewhere on the board
/I2C1_SDA: R10.2, U7.A4 (PB9); also elsewhere on the board
/I2C2_SCL: J7.3, R1.2, U7.J7 (PB10)
/I2C2_SDA: J7.2, R2.2, U7.K7 (PB11)
/INT_HG_IMU_1: U7.A5 (PB7); also elsewhere on the board
/INT_HG_IMU_2: U7.A6 (PB4(NJTRST)); also elsewhere on the board
/INT_IMU_1: U7.A1 (PC14); also elsewhere on the board
/INT_IMU_2: U7.C4 (PE1); also elsewhere on the board
/INT_IMU_3: U7.A3 (PE2); also elsewhere on the board
/INT_IMU_4: U7.A2 (PC13); also elsewhere on the board
/INT_MAG_1: U7.A7 (PB3(JTDO); also elsewhere on the board
/INT_MAG_2: U7.A8 (PA15(JTDI)); also elsewhere on the board
/PYRO_FIRE_1: U7.B6 (PD5); also elsewhere on the board
/PYRO_FIRE_2: U7.B5 (PB6); also elsewhere on the board
/PYRO_SENS_1: U7.F1 (PC0); also elsewhere on the board
/PYRO_SENS_2: U7.F2 (PC1); also elsewhere on the board
/RST: C23.2, J1.5, U7.E1 (NRST)
/SDCard/D0: U7.F9 (PC8); also elsewhere on the board
/SDCard/D1: U7.E9 (PC9); also elsewhere on the board
/SDCard/D2: U7.B9 (PC10); also elsewhere on the board
/SDCard/D3: U7.B8 (PC11); also elsewhere on the board
/SDCard/SCLK: U7.C8 (PC12); also elsewhere on the board
/SDMMC_CMD: U7.B7 (PD2); also elsewhere on the board
/SPI1_CS: J8.5, U7.K2 (PA3)
/SPI1_MISO: J8.3, U7.J3 (PA6)
/SPI1_MOSI: J8.2, U7.K3 (PA7)
/SPI1_SCK: J8.4, U7.H3 (PA5)
/SWD_CLK: J1.2, U7.A9 (PA14(JTCK)
/SWD_DIO: J1.4, U7.A10 (PA13(JTMS)
/TIM3_CH1: R6.1, U7.F10 (PC6)
/TIM3_CH2: R8.1, U7.E10 (PC7)
/TIM12_CH1: BZ1.1 (+), U7.H10 (PB14)
/TIM12_CH2: R7.1, U7.G10 (PB15)
/UART4_RX: J5.3, U7.H2 (PA1)
/UART4_TX: J5.2, U7.G2 (PA0)
/UART5_RX: J2.3, U7.K8 (PB12)
/UART5_TX: J2.2, U7.J8 (PB13)
/UART7_RX: J3.3, U7.H5 (PE7)
/UART7_TX: J3.2, U7.J5 (PE8)
/USB-C_Port/D+: U7.B10 (PA12); also elsewhere on the board
/USB-C_Port/D-: U7.C10 (PA11); also elsewhere on the board
/USB_OTG_ID: U7.D10 (PA10)
GND: BZ1.2 (-), C10.2, C11.2, C12.2, C13.2, C14.2, C15.2, C16.2, C17.2, C19.2, C21.2, C23.1, C27.1, D3.1 (K), D4.1 (K), D5.1 (K), D6.1 (K), J1.3, J2.4, J3.4, J5.4, J7.4, J8.6, NT1.2, R24.1, U7.C2 (VSS), U7.E4 (VSS), U7.E5 (VSS), U7.E6 (VSS), U7.G1 (VSSA), U7.J1 (VSS), Y1.2 (GND); also elsewhere on the board
unnamed: C10.1, U7.F8 (VCAP)
unnamed: C11.1, U7.E7 (VCAP)
unnamed: D3.2 (A), R9.2
unnamed: D4.2 (A), R7.2
unnamed: D5.2 (A), R6.2
unnamed: D6.2 (A), R8.2
unnamed: JP1.2 (B), R23.1, U7.D5 (BOOT0)
unnamed: NT1.1, R23.2, U7.F7 (PDR_ON)
unnamed: R32.2, U7.C1 (PH0)
unnamed: R32.1, Y1.3 (OUT)
VBUS: R26.2; also elsewhere on the board

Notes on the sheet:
Summary of MCU Connections: - 3x UART - 1x I2C - 1x SPI - 1x SWD - 1x SDMMC - 1x USB 2.0 - 4x PWM Pins - 2z GPIO Toggle - 3x Analog In - 1x Buzzer - 2x Pyro Channel Fire Pins - 2x Pyro Channel Sense Pins - 3x LED PWM - 1x Voltage sense
VDD Caps
I2C 2
Assuming NRST pin goes to button, datasheet recommends a 0.1uF Capacitor to protect against parisitic resets.
ESR <= 100 mΩ
Boot(pin) = 0 and BOOT_ADD0(optionbyte) = 0x1FF0
VDD33USB Caps ESR <= 600 mΩ
VDDA Caps
LEDS
24MHZ +- 50ppm
110R gives an output current of about 12 mA assuming input PWM votlage amplitude is 3.3V and assuming V_forward is about 2.0 V
SPI 2
Tri State should be high so the chip outputs a clock signal
VBAT Caps
Connectivity Bus Notes: - ALL UART TX/RX, I2C SDA/SCL, SPI MOSI/MISO/SCK will need to be configured for the pin they are connected to in code. Defaults WILL NOT WORK

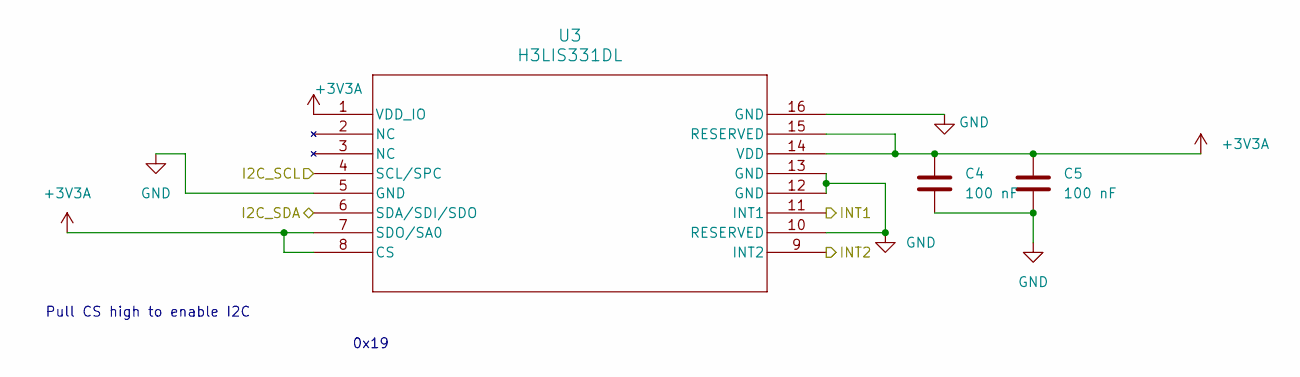
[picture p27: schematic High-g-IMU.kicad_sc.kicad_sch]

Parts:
C4, C5: 100 nF; C_0603_1608Metric_Pad1.08x0.95mm_HandSolder
U3: H3LIS331DL; QFN300X300X100-16N

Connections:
+3V3A: C4.1, C5.1, U3.1 (VDD_IO), U3.7 (SDO/SA0), U3.8 (CS), U3.14 (VDD), U3.15 (RESERVED); also elsewhere on the board
/I2C1_SCL: U3.4 (SCL/SPC); also elsewhere on the board
/I2C1_SDA: U3.6 (SDA/SDI/SDO); also elsewhere on the board
/INT_HG_IMU_1: U3.11 (INT1); also elsewhere on the board
/INT_HG_IMU_2: U3.9 (INT2); also elsewhere on the board
GND: C4.2, C5.2, U3.5 (GND), U3.10 (RESERVED), U3.12 (GND), U3.13 (GND), U3.16 (GND); also elsewhere on the board

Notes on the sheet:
0x19
Pull CS high to enable I2C

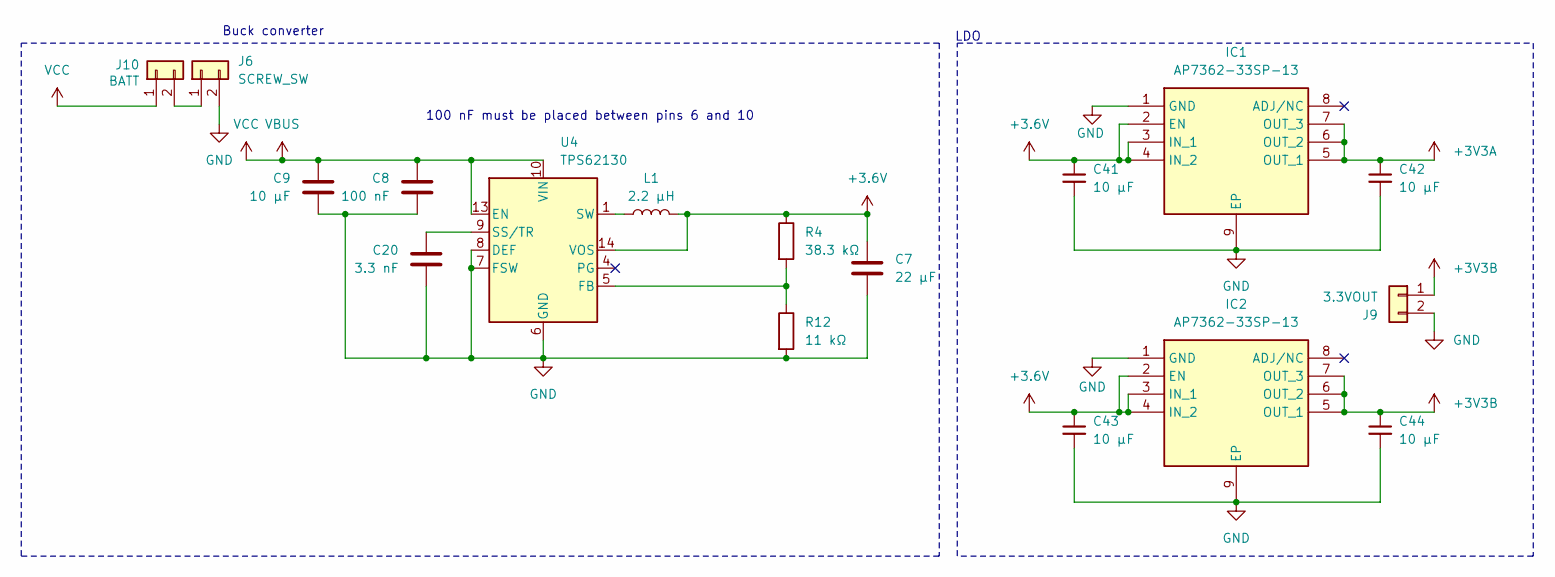
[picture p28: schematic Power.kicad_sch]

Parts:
C7: 22 µF; C_0805_2012Metric_Pad1.18x1.45mm_HandSolder
C8: 100 nF; C_0603_1608Metric_Pad1.08x0.95mm_HandSolder
C9, C41, C42, C43, C44: 10 µF; C_0805_2012Metric_Pad1.18x1.45mm_HandSolder
C20: 3.3 nF; C_0603_1608Metric_Pad1.08x0.95mm_HandSolder
IC1, IC2: AP7362-33SP-13; Diodes_SO-8EP; Mouser Part Number 621-AP7362-33SP-13
J6: SCREW_SW; JST_XH_B2B-XH-A_1x02_P2.50mm_Vertical
J9: 3.3VOUT; JST_XH_B2B-XH-A_1x02_P2.50mm_Vertical
J10: BATT; JST_XH_B2B-XH-A_1x02_P2.50mm_Vertical
L1: 2.2 µH; L_Sumida_CDMC6D28_7.25x6.5mm
R4: 38.3 kΩ; R_0603_1608Metric_Pad0.98x0.95mm_HandSolder
R12: 11 kΩ; R_0603_1608Metric_Pad0.98x0.95mm_HandSolder
U4: TPS62130; VQFN-16-1EP_3x3mm_P0.5mm_EP1.68x1.68mm_ThermalVias

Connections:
+3.6V: C7.1, C41.1, C43.1, IC1.2 (EN), IC1.3 (IN_1), IC1.4 (IN_2), IC2.2 (EN), IC2.3 (IN_1), IC2.4 (IN_2), L1.2, R4.1, U4.14 (VOS)
+3V3A: C42.1, IC1.5 (OUT_1), IC1.6 (OUT_2), IC1.7 (OUT_3); also elsewhere on the board
+3V3B: C44.1, IC2.5 (OUT_1), IC2.6 (OUT_2), IC2.7 (OUT_3), J9.1; also elsewhere on the board
GND: C7.2, C8.2, C9.1, C20.2, C41.2, C42.2, C43.2, C44.2, IC1.1 (GND), IC1.9 (EP), IC2.1 (GND), IC2.9 (EP), J6.2, J9.2, R12.2, U4.6 (GND), U4.7 (FSW), U4.8 (DEF), U4.15 (GND), U4.16 (GND), U4.17 (GND); also elsewhere on the board
unnamed: J6.1, J10.2
unnamed: L1.1, U4.1 (SW), U4.2 (SW), U4.3 (SW)
unnamed: R4.2, R12.1, U4.5 (FB)
unnamed: C20.1, U4.9 (SS/TR)
VBUS: C8.1, C9.2, J10.1, U4.10 (VIN), U4.11 (VIN), U4.12 (VIN), U4.13 (EN); also elsewhere on the board

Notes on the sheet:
100 nF must be placed between pins 6 and 10
Buck converter
LDO

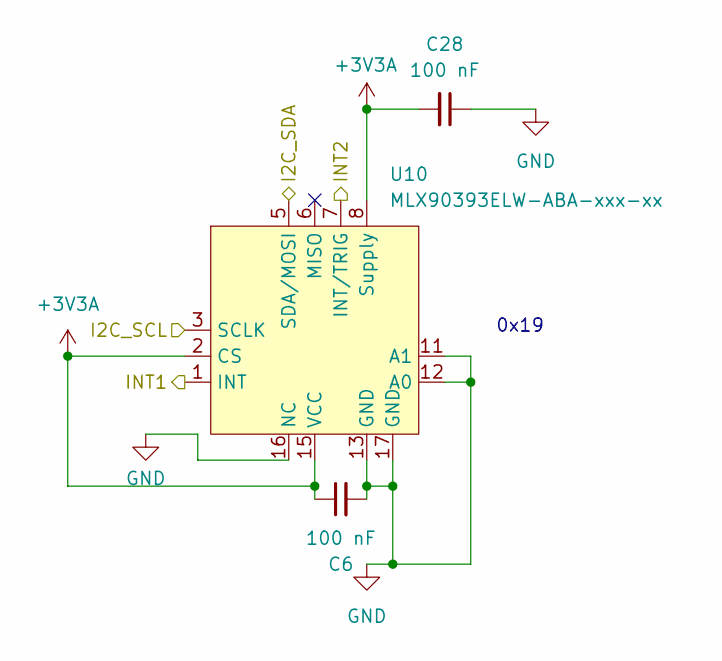
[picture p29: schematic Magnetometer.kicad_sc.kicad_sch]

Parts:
C6, C28: 100 nF; C_0603_1608Metric_Pad1.08x0.95mm_HandSolder
U10: MLX90393ELW-ABA-xxx-xx; QFN-16-1EP_3x3mm_P0.5mm_EP1.75x1.75mm

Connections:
+3V3A: C6.1, C28.2, U10.2 (CS), U10.8 (Supply), U10.15 (VCC); also elsewhere on the board
/I2C1_SCL: U10.3 (SCLK); also elsewhere on the board
/I2C1_SDA: U10.5 (SDA/MOSI); also elsewhere on the board
/INT_MAG_1: U10.1 (INT); also elsewhere on the board
/INT_MAG_2: U10.7 (INT/TRIG); also elsewhere on the board
GND: C6.2, C28.1, U10.4 (NC), U10.9 (NC), U10.10 (NC), U10.11 (A1), U10.12 (A0), U10.13 (GND), U10.14 (NC), U10.16 (NC), U10.17 (GND); also elsewhere on the board

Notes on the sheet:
0x19

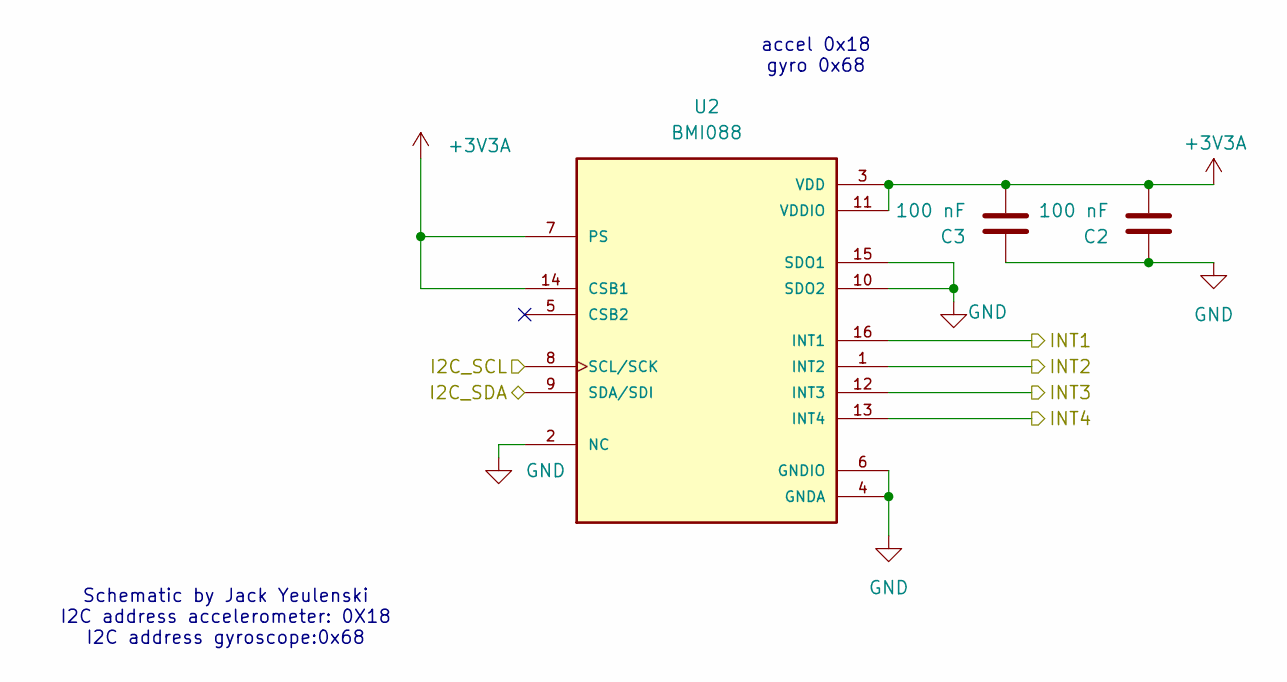
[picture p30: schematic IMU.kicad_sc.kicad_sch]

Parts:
C2, C3: 100 nF; C_0603_1608Metric_Pad1.08x0.95mm_HandSolder
U2: BMI088; Bosch_LGA-16_4.5x3mm_P0.5mm_LayoutBorder7x1y_ClockwisePinNu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

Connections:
+3V3A: C2.2, C3.2, U2.3 (VDD), U2.7 (PS), U2.11 (VDDIO), U2.14 (CSB1); also elsewhere on the board
/I2C1_SCL: U2.8 (SCL/SCK); also elsewhere on the board
/I2C1_SDA: U2.9 (SDA/SDI); also elsewhere on the board
/INT_IMU_1: U2.16 (INT1); also elsewhere on the board
/INT_IMU_2: U2.1 (INT2); also elsewhere on the board
/INT_IMU_3: U2.12 (INT3); also elsewhere on the board
/INT_IMU_4: U2.13 (INT4); also elsewhere on the board
GND: C2.1, C3.1, U2.2 (NC), U2.4 (GNDA), U2.6 (GNDIO), U2.10 (SDO2), U2.15 (SDO1); also elsewhere on the board

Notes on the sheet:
accel 0x18 gyro 0x68
Schematic by Jack Yeulenski I2C address accelerometer: 0X18 I2C address gyroscope:0x68

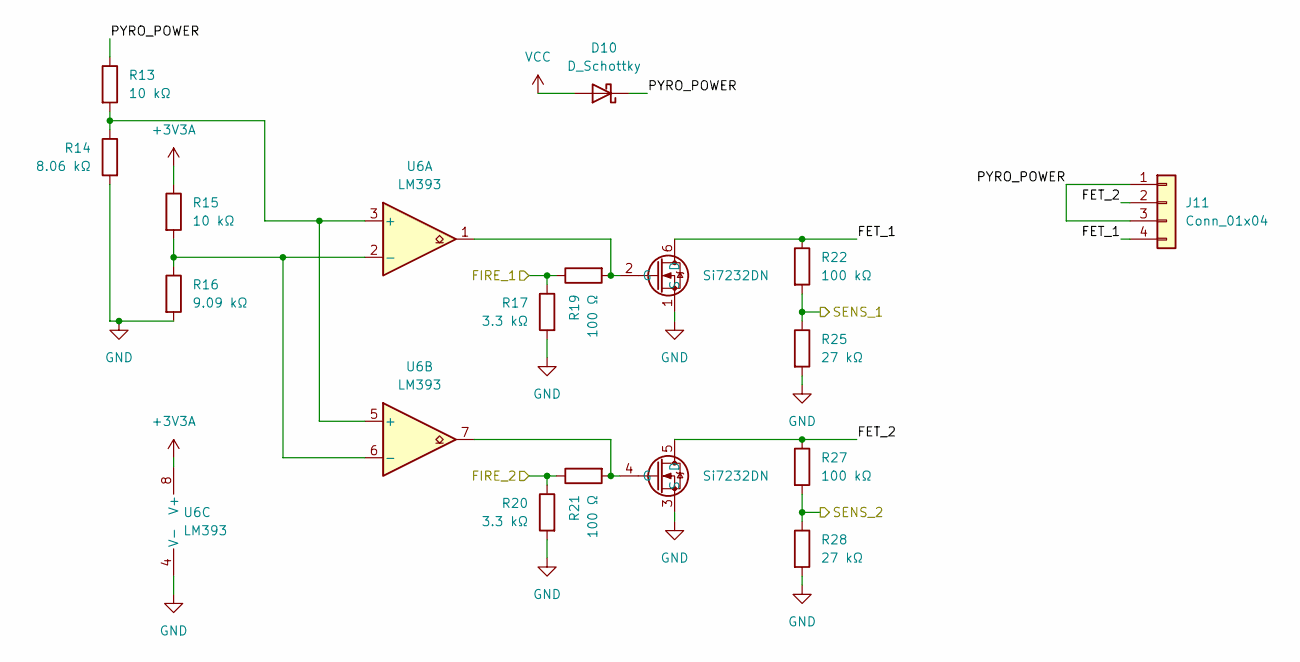
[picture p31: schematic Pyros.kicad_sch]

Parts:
D10: D_Schottky; D_SMA
J11: Conn_01x04; TerminalBlock_Phoenix_PT-1,5-4-3.5-H_1x04_P3.50mm_Horizontal
R13, R15: 10 kΩ; R_0603_1608Metric_Pad0.98x0.95mm_HandSolder
R14: 8.06 kΩ; R_0603_1608Metric_Pad0.98x0.95mm_HandSolder
R16: 9.09 kΩ; R_0603_1608Metric_Pad0.98x0.95mm_HandSolder
R17, R20: 3.3 kΩ; R_0603_1608Metric_Pad0.98x0.95mm_HandSolder
R19, R21: 100 Ω; R_0603_1608Metric_Pad0.98x0.95mm_HandSolder
R22, R27: 100 kΩ; R_0603_1608Metric_Pad0.98x0.95mm_HandSolder
R25, R28: 27 kΩ; R_0603_1608Metric_Pad0.98x0.95mm_HandSolder
U6: LM393; SOIC-8_3.9x4.9mm_P1.27mm
U8: Si7232DN; Vishay_PowerPAK_1212-8_Dual

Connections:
+3V3A: R15.1, U6.8 (V+); also elsewhere on the board
/PYRO_FIRE_1: R17.1, R19.1; also elsewhere on the board
/PYRO_FIRE_2: R20.1, R21.1; also elsewhere on the board
/PYRO_SENS_1: R22.2, R25.1; also elsewhere on the board
/PYRO_SENS_2: R27.2, R28.1; also elsewhere on the board
/Pyros/FET_1: J11.4, R22.1, U8.6 (D)
/Pyros/FET_2: J11.2, R27.1, U8.5 (D)
/Pyros/PYRO_POWER: D10.1 (K), J11.1, J11.3, R13.1
GND: R14.2, R16.2, R17.2, R20.2, R25.2, R28.2, U6.4 (V-), U8.1 (S), U8.3 (S); also elsewhere on the board
unnamed: R13.2, R14.1, U6.3 (+), U6.5 (+)
unnamed: R15.2, R16.1, U6.2 (-), U6.6 (-)
unnamed: R19.2, U6.1, U8.2 (G)
unnamed: R21.2, U6.7, U8.4 (G)
VBUS: D10.2 (A); also elsewhere on the board

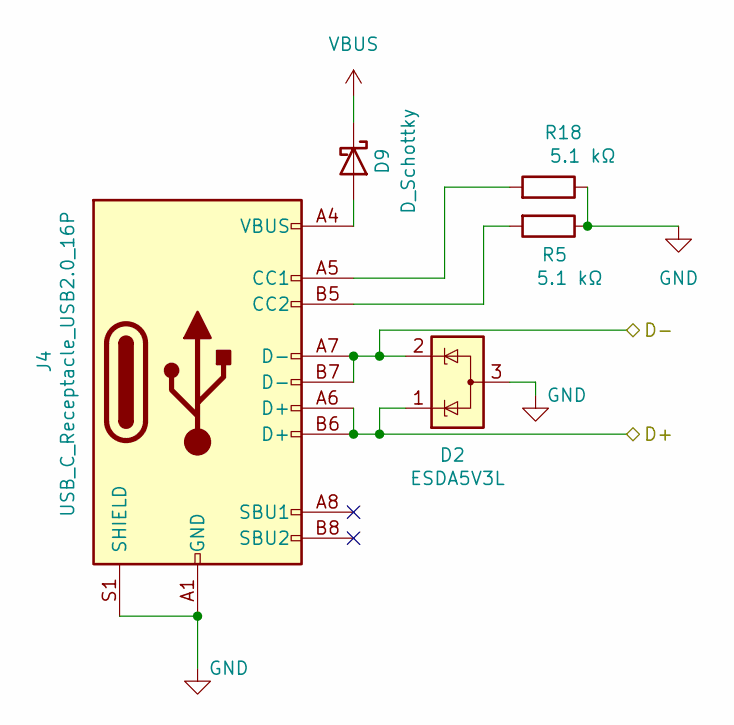
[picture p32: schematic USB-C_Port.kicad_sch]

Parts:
D2: ESDA5V3L; SOT-23-3
D9: D_Schottky; D_0805_2012Metric_Pad1.15x1.40mm_HandSolder
J4: USB_C_Receptacle_USB2.0_16P; USB_C_Receptacle_GCT_USB4105-xx-A_16P_TopMnt_Horizontal
R5, R18: 5.1 kΩ; R_0603_1608Metric_Pad0.98x0.95mm_HandSolder

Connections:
/USB-C_Port/D+: D2.1 (K), J4.A6 (D+), J4.B6 (D+); also elsewhere on the board
/USB-C_Port/D-: D2.2 (K), J4.A7 (D-), J4.B7 (D-); also elsewhere on the board
GND: D2.3 (A), J4.A1 (GND), J4.A12 (GND), J4.B1 (GND), J4.B12 (GND), J4.S1 (SHIELD), R5.1, R18.1; also elsewhere on the board
unnamed: D9.2 (A), J4.A4 (VBUS), J4.A9 (VBUS), J4.B4 (VBUS), J4.B9 (VBUS)
unnamed: J4.A5 (CC1), R18.2
unnamed: J4.B5 (CC2), R5.2
VBUS: D9.1 (K); also elsewhere on the board

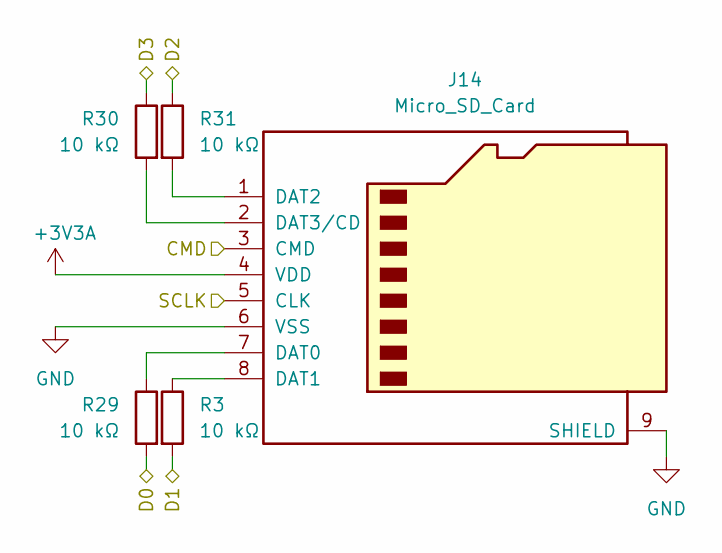
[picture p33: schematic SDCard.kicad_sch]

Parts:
J14: Micro_SD_Card; microSD_HC_Wuerth_693072010801
R3, R29, R30, R31: 10 kΩ; R_0603_1608Metric_Pad0.98x0.95mm_HandSolder

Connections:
+3V3A: J14.4 (VDD); also elsewhere on the board
/SDCard/D0: R29.2; also elsewhere on the board
/SDCard/D1: R3.2; also elsewhere on the board
/SDCard/D2: R31.1; also elsewhere on the board
/SDCard/D3: R30.1; also elsewhere on the board
/SDCard/SCLK: J14.5 (CLK); also elsewhere on the board
/SDMMC_CMD: J14.3 (CMD); also elsewhere on the board
GND: J14.6 (VSS), J14.9 (SHIELD); also elsewhere on the board
unnamed: J14.7 (DAT0), R29.1
unnamed: J14.8 (DAT1), R3.1
unnamed: J14.1 (DAT2), R31.2
unnamed: J14.2 (DAT3/CD), R30.2

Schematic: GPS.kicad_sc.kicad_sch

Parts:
C18, C24: 100 nF; C_0603_1608Metric_Pad1.08x0.95mm_HandSolder
U5: SAM-M10Q-00B; XCVR_SAM-M10Q-00B; PARTREV R03

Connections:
+3V3A: C18.1, C24.1, U5.2 (V_IO), U5.3 (V_BCKP), U5.17 (VCC); also elsewhere on the board
/I2C1_SCL: U5.12 (SCL); also elsewhere on the board
/I2C1_SDA: U5.9 (SDA); also elsewhere on the board
GND: C18.2, C24.2, U5.1 (GND), U5.4 (GND__1), U5.5 (GND__2), U5.6 (GND__3), U5.10 (GND__4), U5.11 (GND__5), U5.15 (GND__6), U5.16 (GND__7), U5.20 (GND__8); also elsewhere on the board

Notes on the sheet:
SAM-M10Q operates at I²C address 0x42 (fixed).

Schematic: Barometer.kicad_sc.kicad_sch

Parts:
C1: 100 nF; C_0603_1608Metric_Pad1.08x0.95mm_HandSolder
U1: MS5611-01BA; LGA-8_3x5mm_P1.25mm

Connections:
+3V3A: C1.1, U1.1 (VDD), U1.2 (PS); also elsewhere on the board
/I2C1_SCL: U1.8 (SCLK); also elsewhere on the board
/I2C1_SDA: U1.7 (SDI/SDA); also elsewhere on the board
GND: C1.2, U1.3 (GND), U1.4 (CSB), U1.5 (CSB); also elsewhere on the board

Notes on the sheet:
I2C 0x76

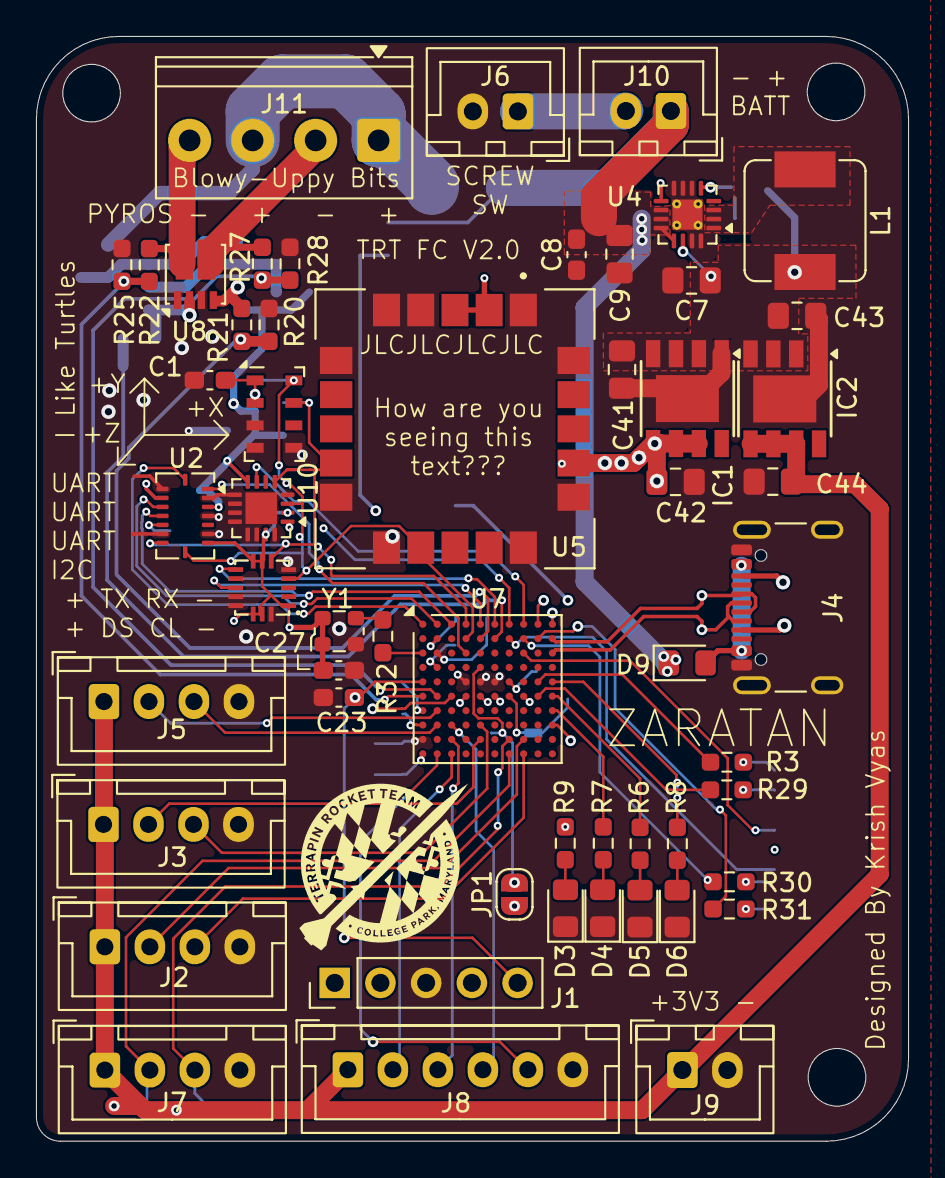
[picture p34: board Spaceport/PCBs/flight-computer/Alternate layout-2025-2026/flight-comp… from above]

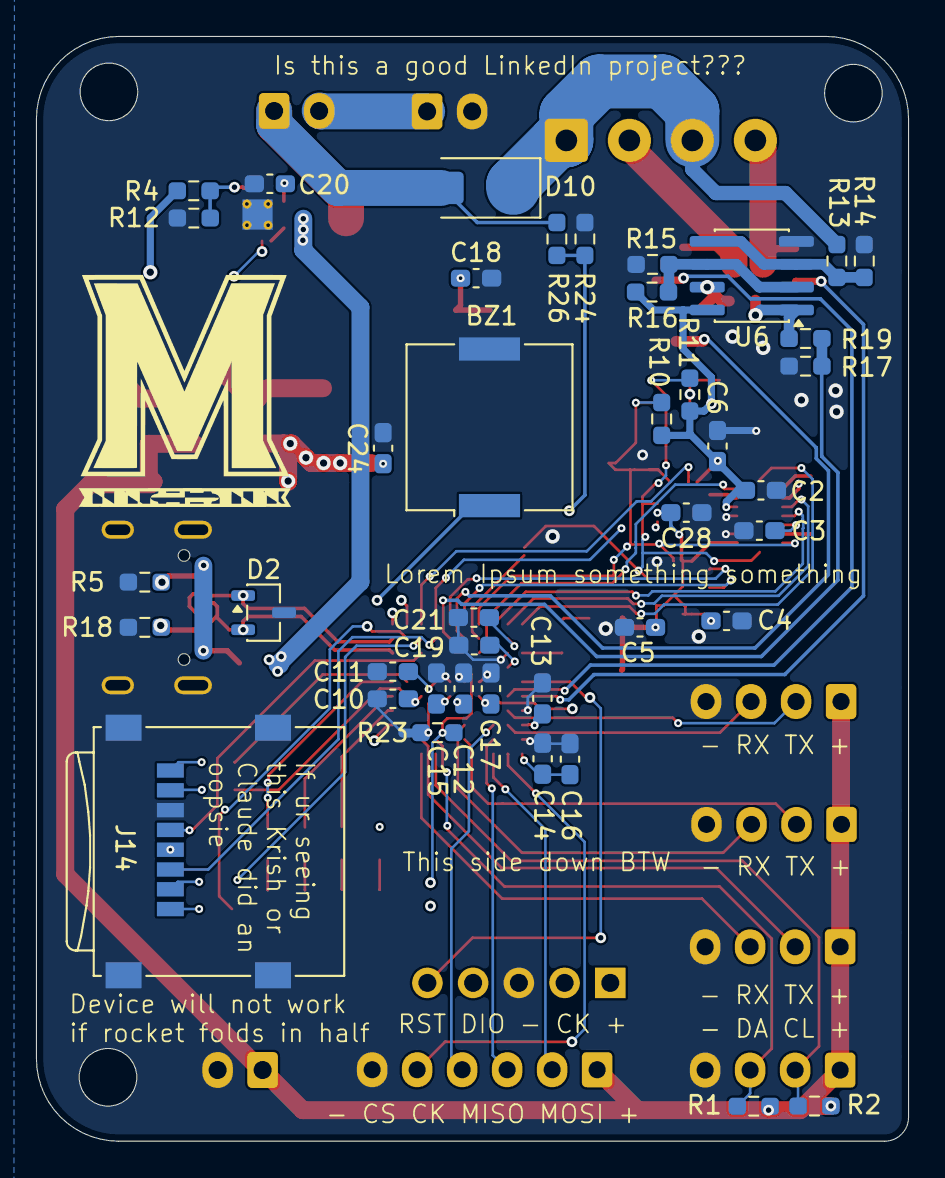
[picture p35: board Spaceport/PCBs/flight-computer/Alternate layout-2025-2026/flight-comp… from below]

Board: 4 copper layers, 48.4 x 61.4 mm, 99 parts (42 on the bottom side), 75 nets.

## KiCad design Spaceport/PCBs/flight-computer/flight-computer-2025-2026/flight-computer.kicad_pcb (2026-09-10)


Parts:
BZ1: Buzzer; Buzzer_TDK_PS1240P02BT_D12.2mm_H6.5mm
C10: 2.2 µF; C_0603_1608Metric_Pad1.08x0.95mm_HandSolder
C11: 2.2uF; C_0603_1608Metric_Pad1.08x0.95mm_HandSolder
C12, C13, C14, C15, C17, C19, C21, C27: 100 nF; C_0603_1608Metric_Pad1.08x0.95mm_HandSolder
C16: 4.7 µF; C_0603_1608Metric_Pad1.08x0.95mm_HandSolder
C23: 0.1uF; C_0603_1608Metric_Pad1.08x0.95mm_HandSolder
D3, D4, D5, D6: LED; LED_0805_2012Metric_Pad1.15x1.40mm_HandSolder
H1, H2, H3, H4: MountingHole; MountingHole_3.2mm_M3_DIN965
J2, J3: Conn_01x02; JST_XH_B2B-XH-A_1x02_P2.50mm_Vertical
J5: UART; JST_XH_B4B-XH-A_1x04_P2.50mm_Vertical
J7: I2C; JST_XH_B4B-XH-A_1x04_P2.50mm_Vertical
J8: SPI; JST_XH_B6B-XH-A_1x06_P2.50mm_Vertical
J11: SWD; JST_XH_B6B-XH-A_1x06_P2.50mm_Vertical
J13: Conn_01x02; PinHeader_1x02_P2.54mm_Vertical
R1, R2, R10, R11: 10k; R_0603_1608Metric_Pad0.98x0.95mm_HandSolder
R6, R7, R8, R9: 110R; R_0603_1608Metric_Pad0.98x0.95mm_HandSolder
R23: 10kR; R_0603_1608Metric_Pad0.98x0.95mm_HandSolder
R26, R27, R28: 170R; R_0603_1608Metric_Pad0.98x0.95mm_HandSolder
U7: STM32H723VEHx; TFBGA-100_8x8mm_Layout10x10_P0.8mm
Y1: ECS-2520S; Oscillator_SMD_ECS_2520MV-xxx-xx-4Pin_2.5x2.0mm

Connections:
+3V3A: C12.1, C13.1, C14.1, C15.1, C16.1, C17.1, C19.1, C21.1, C27.2, J11.1, J13.1, R9.1, R10.1, R11.1, U7.B2 (VBAT), U7.D2 (VDD), U7.F4 (VDD), U7.F5 (VDD), U7.F6 (VDD33USB), U7.H1 (VDDA), U7.K1 (VDD), Y1.1 (Tri-State), Y1.4 (VDD); also elsewhere on the board
+3V3B: J5.1, J7.1, J8.1, R1.1, R2.1; also elsewhere on the board
ADC: R26.2, R27.2, R28.2
BAT+: J3.1; also elsewhere on the board
D+: U7.D10 (PA10); also elsewhere on the board
D-: U7.C9 (PA9); also elsewhere on the board
ESP_RX: U7.E8 (PD1); also elsewhere on the board
ESP_TX: U7.C10 (PA11); also elsewhere on the board
EXT_I2C_SCL: J7.3, R1.2, U7.J7 (PB10)
EXT_I2C_SDA: J7.2, R2.2, U7.K7 (PB11)
EXT_SPI_CLK: J8.4, U7.A3 (PE2)
EXT_SPI_CS: J8.5, U7.C7 (PD3)
EXT_SPI_MISO: J8.3, U7.D3 (PE5)
EXT_SPI_MOSI: J8.2, U7.E3 (PE6)
EXT_UART_RX: J5.3, U7.K8 (PB12)
EXT_UART_TX: J5.2, U7.J8 (PB13)
GND: BZ1.2 (-), C10.2, C11.2, C12.2, C13.2, C14.2, C15.2, C16.2, C17.2, C19.2, C21.2, C23.1, C27.1, D3.1 (K), D4.1 (K), D5.1 (K), D6.1 (K), J2.2, J5.4, J7.4, J8.6, J11.3, R23.2, U7.C2 (VSS), U7.E4 (VSS), U7.E5 (VSS), U7.E6 (VSS), U7.F7 (PDR_ON), U7.G1 (VSSA), U7.J1 (VSS), Y1.2 (GND); also elsewhere on the board
I2C1_SCL: R11.2, U7.B5 (PB6); also elsewhere on the board
I2C1_SDA: R10.2, U7.A5 (PB7); also elsewhere on the board
LED1_PWM: R8.1, U7.K10 (PD12)
LED2_PWM: R6.1, U7.J10 (PD13)
LED3_PWM: R7.1, U7.H10 (PB14)
NRST: C23.2, J11.5, U7.E1 (NRST)
unnamed: BZ1.1 (+), U7.G8 (PD15)
unnamed: C10.1, U7.F8 (VCAP)
unnamed: C11.1, U7.E7 (VCAP)
unnamed: D3.2 (A), R9.2
unnamed: D4.2 (A), R7.2
unnamed: D5.2 (A), R6.2
unnamed: D6.2 (A), R8.2
unnamed: J2.1, J3.2
unnamed: J13.2, R23.1, U7.D5 (BOOT0)
unnamed: R26.1, U7.G2 (PA0)
unnamed: R27.1, U7.H2 (PA1)
unnamed: R28.1, U7.J2 (PA2)
unnamed: U7.C1 (PH0), Y1.3 (OUT)
SDMMC1_CK: U7.C8 (PC12); also elsewhere on the board
SDMMC1_CMD: U7.B7 (PD2); also elsewhere on the board
SDMMC1_D0: U7.F9 (PC8); also elsewhere on the board
SDMMC1_D1: U7.E9 (PC9); also elsewhere on the board
SDMMC1_D2: U7.B9 (PC10); also elsewhere on the board
SDMMC1_D3: U7.B8 (PC11); also elsewhere on the board
SWD_CLK: J11.2, U7.A9 (PA14(JTCK)
SWD_DIO: J11.4, U7.A10 (PA13(JTMS)

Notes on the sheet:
VDD Caps
According to datasheet, any pin with FT_ha can be changed (in code) to an analog option. For 16 bit resolution, it's recommended to use 170 ohm resistor in series
I2C 2
UART 4
Assuming NRST pin goes to button, datasheet recommends a 0.1uF Capacitor to protect against parisitic resets.
:=_u USB option (supplied by VDD33USB)
ESR <= 100 mΩ
KV 11/25 - Removed D10 Global label
Boot(pin) = 0 and BOOT_ADD0(optionbyte) = 0x1FF0
VDD33USB Caps ESR <= 600 mΩ
VDDA Caps
LEDS
:=_h High-speed low-voltage I/O :=FT (5V)
24MHZ +- 50ppm
110R gives an output current of about 12 mA assuming input PWM votlage amplitude is 3.3V and assuming V_forward is about 2.0 V
SPI 2
Tri State should be high so the chip outputs a clock signal
BATTERY | SCREW SWITCH
VBAT Caps
KV 11/25 - Changed switch to jumper


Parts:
C4, C5: 100nF; C_0603_1608Metric_Pad1.08x0.95mm_HandSolder
JP9: 0x19; SolderJumper-2_P1.3mm_Open_RoundedPad1.0x1.5mm
JP10: 0x18; SolderJumper-2_P1.3mm_Open_RoundedPad1.0x1.5mm
U3: H3LIS331DL; QFN300X300X100-16N

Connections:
+3V3A: C4.1, C5.1, JP9.2 (B), U3.1 (VDD_IO), U3.8 (CS), U3.14 (VDD), U3.15 (RESERVED); also elsewhere on the board
GND: C4.2, C5.2, JP10.1 (A), U3.5 (GND), U3.10 (RESERVED), U3.12 (GND), U3.13 (GND), U3.16 (GND); also elsewhere on the board
I2C1_SCL: U3.4 (SCL/SPC); also elsewhere on the board
I2C1_SDA: U3.6 (SDA/SDI/SDO); also elsewhere on the board
unnamed: JP9.1 (A), JP10.2 (B), U3.7 (SDO/SA0)

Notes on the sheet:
Pull CS high to enable I2C


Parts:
C9, C39: 22uF; C_0603_1608Metric_Pad1.08x0.95mm_HandSolder
C20: 330uF; CP_Elec_10x10
C22, C26, C31: 100nF; C_0603_1608Metric_Pad1.08x0.95mm_HandSolder
C25: 27pF; C_0603_1608Metric_Pad1.08x0.95mm_HandSolder
C29: 620pF; C_0603_1608Metric_Pad1.08x0.95mm_HandSolder
C30: 10uF; C_0603_1608Metric_Pad1.08x0.95mm_HandSolder
C32: 2.2uF; C_0603_1608Metric_Pad1.08x0.95mm_HandSolder
C38: DNP; not fitted
C40: 4.7uF; C_0603_1608Metric_Pad1.08x0.95mm_HandSolder
IC1, IC2: AP7362-33SP-13; Diodes_SO-8EP; Mouser Part Number 621-AP7362-33SP-13
J9: 3.3VOUT; JST_XH_B2B-XH-A_1x02_P2.50mm_Vertical
J10: 5.0VOUT; JST_XH_B2B-XH-A_1x02_P2.50mm_Vertical
L1: 2.2uH; L_0805_2012Metric_Pad1.05x1.20mm_HandSolder
L3: 1uH; L_0805_2012Metric_Pad1.05x1.20mm_HandSolder
L4: 1.8uH; L_0805_2012Metric_Pad1.05x1.20mm_HandSolder
PS1: TPS61288LRQQR; Texas_VQFN-HR-20_3x2.5mm_P0.5mm_RQQ0011A; PARTREV C
R12: 15k; R_0603_1608Metric_Pad0.98x0.95mm_HandSolder
R13: 111k; R_0603_1608Metric_Pad0.98x0.95mm_HandSolder
R14: 28.7k; R_0603_1608Metric_Pad0.98x0.95mm_HandSolder
R16: 500k; R_0603_1608Metric_Pad0.98x0.95mm_HandSolder
R17: 100k; R_0603_1608Metric_Pad0.98x0.95mm_HandSolder
U6: TPS62A03DRLR; SOT-563

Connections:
+3V3A: IC1.5 (OUT_1), IC1.6 (OUT_2), IC1.7 (OUT_3); also elsewhere on the board
+3V3B: IC2.5 (OUT_1), IC2.6 (OUT_2), IC2.7 (OUT_3), J9.1; also elsewhere on the board
/Power/3.6V: C38.1, C39.1, IC1.2 (EN), IC1.3 (IN_1), IC1.4 (IN_2), IC2.2 (EN), IC2.3 (IN_1), IC2.4 (IN_2), L3.2, R16.1
/Power/5V: C9.2, C20.1, C26.2, C40.1, J10.1, L4.2, U6.3 (VIN), U6.4 (EN)
/Power/SW: C31.1, L1.2, PS1.4 (SW), PS1.9 (SW__1)
BAT_CHARGER: C22.1, C30.1, L1.1, PS1.6 (EN), PS1.7 (VIN); also elsewhere on the board
GND: C9.1, C20.2, C22.2, C25.2, C26.1, C30.2, C32.2, C39.2, C40.2, IC1.1 (GND), IC1.9 (EP), IC2.1 (GND), IC2.9 (EP), J9.2, J10.2, PS1.3 (PGND), PS1.10 (AGND), R12.2, R14.2, R17.2, U6.1 (GND); also elsewhere on the board
unnamed: C29.2, R14.1
unnamed: C31.2, PS1.8 (BST)
unnamed: C29.1, PS1.2 (COMP)
unnamed: C25.1, PS1.1 (FB), R12.1, R13.2
unnamed: C32.1, PS1.11 (VCC)
unnamed: L4.1, PS1.5 (VOUT), R13.1
unnamed: C38.2, R16.2, R17.1, U6.5 (FB)
unnamed: L3.1, U6.2 (SW)

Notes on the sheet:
VIN 2.5V TO 5.5V
BUCK
VOUT 3.6V
CFF is optional
VOUT 5.04V
BOOST
LDO
KV 11/25 - Made footprint DNP


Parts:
C6, C28: 100 nF; C_0603_1608Metric_Pad1.08x0.95mm_HandSolder
JP1: 000111X; SolderJumper-2_P1.3mm_Open_RoundedPad1.0x1.5mm
JP2: 000110X; SolderJumper-2_P1.3mm_Open_RoundedPad1.0x1.5mm
JP3: 00011X1; SolderJumper-2_P1.3mm_Open_RoundedPad1.0x1.5mm
JP4: 00011X0; SolderJumper-2_P1.3mm_Open_RoundedPad1.0x1.5mm
U10: MLX90393ELW-ABA-xxx-xx; QFN-16-1EP_3x3mm_P0.5mm_EP1.75x1.75mm

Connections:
+3V3A: C6.1, C28.2, JP1.2 (B), JP3.2 (B), U10.2 (CS), U10.8 (Supply), U10.15 (VCC); also elsewhere on the board
GND: C6.2, C28.1, JP2.2 (B), JP4.2 (B), U10.13 (GND); also elsewhere on the board
I2C1_SCL: U10.3 (SCLK); also elsewhere on the board
I2C1_SDA: U10.5 (SDA/MOSI); also elsewhere on the board
unnamed: JP1.1 (A), JP2.1 (A), U10.11 (A1)
unnamed: JP3.1 (A), JP4.1 (A), U10.12 (A0)


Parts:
C2, C3: 100nF; C_0603_1608Metric_Pad1.08x0.95mm_HandSolder
JP5: Accel 0x19; SolderJumper-2_P1.3mm_Open_RoundedPad1.0x1.5mm
JP6: Accel 0x18; SolderJumper-2_P1.3mm_Open_RoundedPad1.0x1.5mm
JP7: Gyro 0x69; SolderJumper-2_P1.3mm_Open_RoundedPad1.0x1.5mm
JP8: Accel 0x68; SolderJumper-2_P1.3mm_Open_RoundedPad1.0x1.5mm
U2: BMI088; PQFN50P450X300X100-16N

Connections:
+3V3A: C2.2, C3.2, JP5.2 (B), JP7.2 (B), U2.3 (VDD), U2.7 (PS), U2.11 (VDDIO), U2.14 (CSB1); also elsewhere on the board
GND: C2.1, C3.1, JP6.1 (A), JP8.1 (A), U2.2 (NC), U2.4 (GNDA), U2.6 (GNDIO); also elsewhere on the board
I2C1_SCL: U2.8 (SCL/SCK); also elsewhere on the board
I2C1_SDA: U2.9 (SDA/SDI); also elsewhere on the board
unnamed: JP5.1 (A), JP6.2 (B), U2.15 (SDO1)
unnamed: JP7.1 (A), JP8.2 (B), U2.10 (SDO2)

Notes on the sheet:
Schematic by Jack Yeulenski I2C address accelerometer: 0X18 I2C address gyroscope:0x68


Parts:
D2: ESDA5V3L; SOT-23-3
D9: D_Schottky; D_0805_2012Metric_Pad1.15x1.40mm_HandSolder
J4: USB_C_Receptacle_USB2.0_16P; USB_C_Receptacle_G-Switch_GT-USB-7010ASV
R5, R18: 5.1 k; R_0603_1608Metric_Pad0.98x0.95mm_HandSolder

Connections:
+VBUS: D9.1 (K); also elsewhere on the board
D+: D2.1 (K), J4.A6 (D+), J4.B6 (D+); also elsewhere on the board
D-: D2.2 (K), J4.A7 (D-), J4.B7 (D-); also elsewhere on the board
GND: D2.3 (A), J4.A1 (GND), J4.A12 (GND), J4.B1 (GND), J4.B12 (GND), J4.S1 (SHIELD), R5.1, R18.1; also elsewhere on the board
unnamed: D9.2 (A), J4.A4 (VBUS), J4.A9 (VBUS), J4.B4 (VBUS), J4.B9 (VBUS)
unnamed: J4.A5 (CC1), R18.2
unnamed: J4.B5 (CC2), R5.2

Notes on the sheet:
0402


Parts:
C7: 1uF; C_0603_1608Metric_Pad1.08x0.95mm_HandSolder
C8, C33, C36: 10uF; C_0603_1608Metric_Pad1.08x0.95mm_HandSolder
C34: 47nF; C_0603_1608Metric_Pad1.08x0.95mm_HandSolder
C35: 4.7uF; C_0603_1608Metric_Pad1.08x0.95mm_HandSolder
C37: 20uF; C_0805_2012Metric_Pad1.18x1.45mm_HandSolder
D1, D7: LED; LED_0805_2012Metric_Pad1.15x1.40mm_HandSolder
D8: D_Schottky; D_0805_2012Metric_Pad1.15x1.40mm_HandSolder
J12: Charge; JST_XH_B2B-XH-A_1x02_P2.50mm_Vertical
L2: 1uH; L_0805_2012Metric_Pad1.05x1.20mm_HandSolder
R3: 225; R_0603_1608Metric_Pad0.98x0.95mm_HandSolder
R4: 160; R_0603_1608Metric_Pad0.98x0.95mm_HandSolder
R15, R20: 2k; R_0603_1608Metric_Pad0.98x0.95mm_HandSolder
R21, R22: 100k; R_0603_1608Metric_Pad0.98x0.95mm_HandSolder
U8: BQ25606RGER; Texas_RGE0024H_VQFN-24-1EP_4x4mm_P0.5mm_EP2.7x2.7mm

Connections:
+VBUS: C7.1, D8.1 (K), U8.1 (VAC), U8.24 (VBUS); also elsewhere on the board
/Battery Charger/BTST: C34.1, U8.21 (BTST)
/Battery Charger/REGN: C35.1, R21.1, U8.22 (REGN)
BAT+: C36.1, U8.13 (BAT-1), U8.14 (BAT); also elsewhere on the board
BAT_CHARGER: C33.1, C37.1, L2.1, U8.15 (SYS-1), U8.16 (SYS); also elsewhere on the board
GND: C7.2, C8.1, C33.2, C35.2, C36.2, C37.2, D1.2 (A), D7.2 (A), J12.2, R3.1, R4.1, R22.2, U8.6 (OTG), U8.9 (~CE), U8.17 (GND-1), U8.18 (GND), U8.25 (PAD); also elsewhere on the board
unnamed: D1.1 (K), R15.2
unnamed: D7.1 (K), R20.2
unnamed: D8.2 (A), J12.1
unnamed: R3.2, U8.10 (ICHG)
unnamed: R4.2, U8.8 (ILIM)
unnamed: C8.2, U8.23 (PMID)
unnamed: R15.1, U8.5 (STAT)
unnamed: C34.2, L2.2, U8.19 (SW-1), U8.20 (SW)
unnamed: R21.2, R22.1, U8.11 (TS)
unnamed: R20.1, U8.7 (~PG)

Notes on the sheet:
INPUT
SYSTEM
BATTERY


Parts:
J6: UART; JST_XH_B6B-XH-A_1x06_P2.50mm_Vertical
R19: 10k; R_0603_1608Metric_Pad0.98x0.95mm_HandSolder
U9: ESP32-S3-MINI-1-N4R2; ESP32-S2-MINI-1; PARTREV v0.6

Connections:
+3V3A: J6.1, R19.1, U9.3 (3V3); also elsewhere on the board
/ESP32/EN: J6.5, R19.2, U9.45 (EN)
/ESP32/IO0: J6.2, U9.4 (IO0)
ESP_RX: J6.4, U9.40 (RXD0); also elsewhere on the board
ESP_TX: J6.3, U9.39 (TXD0); also elsewhere on the board
GND: J6.6, U9.1 (GND), U9.2 (GND__1), U9.42 (GND__2), U9.43 (GND__3), U9.46 (GND__4), U9.47 (GND__5), U9.48 (GND__6), U9.49 (GND__7), U9.50 (GND__8), U9.51 (GND__9), U9.52 (GND__10), U9.53 (GND__11), U9.54 (GND__12), U9.55 (GND__13), U9.56 (GND__14), U9.57 (GND__15), U9.58 (GND__16), U9.59 (GND__17), U9.60 (GND__18), U9.61 (GND__19), U9.61_1 (GND__20), U9.61_2 (GND__21), U9.61_3 (GND__22), U9.61_4 (GND__23), U9.61_5 (GND__24), U9.61_6 (GND__25), U9.61_7 (GND__26), U9.61_8 (GND__27), U9.62 (GND__28), U9.63 (GND__29), U9.64 (GND__30), U9.65 (GND__31); also elsewhere on the board

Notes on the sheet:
Small pitch dupont

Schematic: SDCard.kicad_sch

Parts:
J14: Micro_SD_Card; microSD_HC_Wuerth_693072010801

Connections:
+3V3A: J14.4 (VDD); also elsewhere on the board
GND: J14.6 (VSS), J14.9 (SHIELD); also elsewhere on the board
SDMMC1_CK: J14.5 (CLK); also elsewhere on the board
SDMMC1_CMD: J14.3 (CMD); also elsewhere on the board
SDMMC1_D0: J14.7 (DAT0); also elsewhere on the board
SDMMC1_D1: J14.8 (DAT1); also elsewhere on the board
SDMMC1_D2: J14.1 (DAT2); also elsewhere on the board
SDMMC1_D3: J14.2 (DAT3/CD); also elsewhere on the board

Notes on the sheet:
I doubt we need external pull-up resistors. Here is what it says: Each STM32 GPIO offers the possibility to select internal pull-up and pull-down (typical value = 40 kOhm). Some STM32 applications may require to use an external pull-up resistor. This section presents output and input levels compati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
KV 11/25 - Symbol/footprint change

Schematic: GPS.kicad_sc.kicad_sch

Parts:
C18, C24: 100 nF; C_0603_1608Metric_Pad1.08x0.95mm_HandSolder
U5: SAM-M10Q-00B; XCVR_SAM-M10Q-00B; PARTREV R03

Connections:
+3V3A: C18.1, C24.1, U5.2 (V_IO), U5.3 (V_BCKP), U5.17 (VCC); also elsewhere on the board
GND: C18.2, C24.2, U5.1 (GND), U5.4 (GND__1), U5.5 (GND__2), U5.6 (GND__3), U5.10 (GND__4), U5.11 (GND__5), U5.15 (GND__6), U5.16 (GND__7), U5.20 (GND__8); also elsewhere on the board
I2C1_SCL: U5.12 (SCL); also elsewhere on the board
I2C1_SDA: U5.9 (SDA); also elsewhere on the board

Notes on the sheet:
SAM-M10Q operates at I²C address 0x42 (fixed).

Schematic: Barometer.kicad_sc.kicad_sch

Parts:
C1: 100 nF; C_0603_1608Metric_Pad1.08x0.95mm_HandSolder
JP11: 0x76; SolderJumper-2_P1.3mm_Open_RoundedPad1.0x1.5mm
JP12: 0x77; SolderJumper-2_P1.3mm_Open_RoundedPad1.0x1.5mm
U1: MS5611-01BA; LGA-8_3x5mm_P1.25mm

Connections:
+3V3A: C1.1, JP11.1 (A), U1.1 (VDD), U1.2 (PS); also elsewhere on the board
GND: C1.2, JP12.1 (A), U1.3 (GND); also elsewhere on the board
I2C1_SCL: U1.8 (SCLK); also elsewhere on the board
I2C1_SDA: U1.7 (SDI/SDA); also elsewhere on the board
unnamed: JP11.2 (B), JP12.2 (B), U1.4 (CSB), U1.5 (CSB)

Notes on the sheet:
I2C 0X77



Board: 4 copper layers, 70.1 x 50.9 mm, 121 parts (45 on the bottom side), 80 nets.

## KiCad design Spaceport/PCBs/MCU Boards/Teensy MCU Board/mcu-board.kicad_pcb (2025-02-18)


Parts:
BZ1: Buzzer; Buzzer_12x9.5RM7.6
D1, D2: LED; LED_0805_2012Metric_Pad1.15x1.40mm_HandSolder
H1, H2, H3, H4: MountingHole; MountingHole_3.2mm_M3
J1: I2C0; JST_EH_B4B-EH-A_1x04_P2.50mm_Vertical
J2: I2C2; JST_EH_B4B-EH-A_1x04_P2.50mm_Vertical
J3: 5v; JST_EH_B2B-EH-A_1x02_P2.50mm_Vertical
J4: Switch; JST_EH_B2B-EH-A_1x02_P2.50mm_Vertical
J6: UART1; JST_EH_B4B-EH-A_1x04_P2.50mm_Vertical
J7, J8: UART2; JST_EH_B4B-EH-A_1x04_P2.50mm_Vertical
R1, R2, R3, R4: 5k1; R_0805_2012Metric_Pad1.20x1.40mm_HandSolder
R5, R6: 2k; R_0805_2012Metric_Pad1.20x1.40mm_HandSolder
Teensy4.1: Teensy_4.1

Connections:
+3.3V: J1.1, J2.1, J6.1, J7.1, J8.1, R1.2, R2.1, R3.2, R4.1, R5.1, Teensy4.1.14 (3.3V), Teensy4.1.45 (3.3V); also elsewhere on the board
+5V: J3.1, Teensy4.1.47 (Vin); also elsewhere on the board
/RX1: J6.2, Teensy4.1.1 (RX1); also elsewhere on the board
/RX2: J7.2, Teensy4.1.8 (RX2); also elsewhere on the board
/RX8: J8.2, Teensy4.1.26 (TX8); also elsewhere on the board
/SCL0: J1.3, R2.2, Teensy4.1.40 (SCL); also elsewhere on the board
/SCL2: J2.3, R4.2, Teensy4.1.15 (SCL2); also elsewhere on the board
/SDA0: J1.2, R1.1, Teensy4.1.39 (SDA); also elsewhere on the board
/SDA2: J2.2, R3.1, Teensy4.1.16 (SDA2); also elsewhere on the board
/TX1: J6.3, Teensy4.1.2 (TX1); also elsewhere on the board
/TX2: J7.3, Teensy4.1.9 (TX2); also elsewhere on the board
/TX8: J8.3, Teensy4.1.25 (RX8); also elsewhere on the board
GND: BZ1.2 (-), D1.1 (K), D2.1 (K), J1.4, J2.4, J4.1, J6.4, J7.4, J8.4, Teensy4.1.0 (GND), Teensy4.1.33 (GND), Teensy4.1.46 (GND); also elsewhere on the board
unnamed 24: BZ1.1 (+), Teensy4.1.24 (PWM); also elsewhere on the board
unnamed: D1.2 (A), R5.2
unnamed: D2.2 (A), R6.1
unnamed: J3.2, J4.2
unnamed 28: R6.2, Teensy4.1.23 (GPIO); also elsewhere on the board

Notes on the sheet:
I²C Connectors
UART Connectors



Board: 4 copper layers, 32.0 x 62.0 mm, 21 parts (7 on the bottom side), 18 nets.

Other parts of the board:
Teensy4.2: Teensy_4.1

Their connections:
+3.3V: Teensy4.2.14 (3.3V), Teensy4.2.45 (3.3V); also elsewhere on the board
+5V: Teensy4.2.47 (Vin); also elsewhere on the board
/RX1: Teensy4.2.1 (RX1); also elsewhere on the board
/RX2: Teensy4.2.8 (RX2); also elsewhere on the board
/RX8: Teensy4.2.25 (RX8); also elsewhere on the board
/SCL0: Teensy4.2.40 (SCL); also elsewhere on the board
/SCL2: Teensy4.2.15 (SCL2); also elsewhere on the board
/SDA0: Teensy4.2.39 (SDA); also elsewhere on the board
/SDA2: Teensy4.2.16 (SDA2); also elsewhere on the board
/TX1: Teensy4.2.2 (TX1); also elsewhere on the board
/TX2: Teensy4.2.9 (TX2); also elsewhere on the board
/TX8: Teensy4.2.26 (TX8); also elsewhere on the board
GND: Teensy4.2.0 (GND), Teensy4.2.33 (GND), Teensy4.2.46 (GND); also elsewhere on the board
unnamed 24: Teensy4.2.24 (PWM); also elsewhere on the board
unnamed 28: Teensy4.2.23 (GPIO); also elsewhere on the board

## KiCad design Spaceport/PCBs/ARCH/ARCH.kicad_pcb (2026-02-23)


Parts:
5V0: LED; LED_0805_2012Metric_Pad1.15x1.40mm_HandSolder
BAT_PG1: LED; LED_0805_2012Metric_Pad1.15x1.40mm_HandSolder
BSTAT1: LED; LED_0805_2012Metric_Pad1.15x1.40mm_HandSolder
BZ1: Buzzer; LP_Buzzer_CMT-7525-80
C1: 22uF; C_0805_2012Metric
C2, C30, C33, C36: 10uF; C_0805_2012Metric
C3, C4: 1uF; C_0805_2012Metric
C7: 4.7u; C_0805_2012Metric
C8, C9: 47pF; C_0805_2012Metric
C10: 100n; C_0805_2012Metric
C20: 220uF; CP_Radial_D5.0mm_P2.00mm
C25: 27pF; C_0603_1608Metric
C26, C31: 100nF; C_0603_1608Metric
C29: 620pF; C_0603_1608Metric
C32: 2.2uF; C_0805_2012Metric
C34: 47nF; C_0805_2012Metric
C35: 4.7uF; C_0603_1608Metric
D8: D_Schottky; Schottky_3A_DO-214AC_SMA
FB1: FerriteBead; R_0805_2012Metric_Pad1.20x1.40mm_HandSolder
H1, H2, H3, H4: MountingHole; MountingHole_3.2mm_M3
J1: Conn_01x05_Pin; JST_XH_S5B-XH-A_1x05_P2.50mm_Horizontal
J2: PinSocket_2x20_P2.54mm_Vertical
J4, J7: Conn_01x02; JST_XH_S2B-XH-A_1x02_P2.50mm_Horizontal
J6: Conn_01x04_Pin; JST_XH_S4B-XH-A_1x04_P2.50mm_Horizontal
J10: USB_C_Receptacle_USB2.0_16P; USB_C_Receptacle_GCT_USB4105-xx-A_16P_TopMnt_Horizontal
J12: Charge; JST_XH_S2B-XH-A_1x02_P2.50mm_Horizontal
L1, L4: 2.2uH; IND_AMRM00101040_PUL
L2: 1uH; IND_AMRM00101040_PUL
NTF_SW1: SW_Push; SW_EVQ-P7J01P
PS1: TPS61288LRQQR; CONV_TPS61288LRQQR; PARTREV C
R1: 111k; R_0603_1608Metric
R2: 15k; R_0603_1608Metric
R3, R4: 100k; R_0603_1608Metric
R5, R8, R11, R15, R16, R17, R18, R19, R20, R21, R22, R23: 2k; R_0603_1608Metric
R6: 225; R_0603_1608Metric
R7: 160; R_0603_1608Metric
R9, R10: 5.1k; R_0402_1005Metric
R12, R13: 27; R_0805_2012Metric
R14: 28.7k; R_0603_1608Metric
STAT1: LED; LED_0805_2012Metric_Pad1.15x1.40mm_HandSolder
U1, U2: 74AUP1G80; SN74AUP1G80DRYR
U3: TLV77033PDQNR
U4: FT234XD
U5: USBLC6-2P6
U8: BQ25606RGER
VBus1: LED; LED_0805_2012Metric_Pad1.15x1.40mm_HandSolder
WIFI_SW1: SW_Push; SW_EVQ-P7J01P

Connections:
+5V: 5V0.2 (A), C1.1, C20.1, C26.1, J2.2 (5V), J2.4 (5V), J6.1, L4.2
BAT_PG1: BAT_PG1.1 (K), U8.7 (~PG); also elsewhere on the board
BSTAT1: BSTAT1.1 (K), U8.5 (STAT); also elsewhere on the board
BTST: C34.1, U8.21 (BTST)
D+: C8.2, R12.2, U5.6 (I/O1)
D-: C9.2, R13.2, U5.4 (I/O2)
EN: PS1.6 (EN), R11.1, U1.1 (D), U1.4 (~Q)
GND: BZ1.2 (-), C1.2, C2.1, C3.2, C4.2, C7.1, C8.1, C9.1, C10.1, C20.2, C25.2, C26.2, C30.2, C32.2, C33.1, C35.2, C36.1, J1.1, J2.6 (GND), J2.9 (GND), J2.14 (GND), J2.20 (GND), J2.25 (GND), J2.30 (GND), J2.34 (GND), J2.39 (GND), J6.2, J7.2, J10.A1 (GND), J10.A12 (GND), J10.B1 (GND), J10.B12 (GND), J10.S1 (SHIELD), J12.2, PS1.3 (PGND), PS1.10 (AGND), R2.2, R4.2, R5.2, R6.1, R7.1, R9.1, R10.1, R11.2, R14.2, R15.2, R16.2, R17.2, R18.2, R21.2, R22.2, R23.2, U1.3 (GND), U2.3 (GND), U3.2 (GND), U3.5 (GND), U4.5 (GND), U4.13 (GND), U5.2 (GND), U8.6 (OTG), U8.17 (GND-1), U8.18 (GND)
IN_TG: J1.3, R22.1, U2.2 (C)
unnamed: 5V0.1 (K), R16.1
unnamed 10: BAT_PG1.2 (A), R19.1; also elsewhere on the board
unnamed 11: BSTAT1.2 (A), R20.1; also elsewhere on the board
unnamed: BZ1.1 (+), J2.37 (GPIO26)
unnamed: C29.2, R14.1
unnamed: C3.1, D8.1 (K), J12.1, U8.1 (VAC), U8.24 (VBUS)
unnamed 15: J2.1 (3.3V), NTF_SW1.2, WIFI_SW1.2; also elsewhere on the board
unnamed 16: J2.33 (GPIO13), NTF_SW1.1, R23.1; also elsewhere on the board
unnamed 17: J2.35 (GPIO19), R15.1, WIFI_SW1.1; also elsewhere on the board
unnamed: J4.2, J7.1
unnamed: J10.A5 (CC1), R9.2
unnamed: J10.B5 (CC2), R10.2
unnamed: J10.A6 (D+), J10.B6 (D+), U5.1 (I/O1)
unnamed: J10.A7 (D-), J10.B7 (D-), U5.3 (I/O2)
unnamed: C31.2, PS1.8 (BST)
unnamed: C29.1, PS1.2 (COMP)
unnamed: C25.1, PS1.1 (FB), R1.2, R2.1
unnamed: C31.1, L1.2, PS1.4 (SW), PS1.9 (SW__1)
unnamed: C32.1, PS1.11 (VCC)
unnamed: L4.1, PS1.5 (VOUT), R1.1
unnamed: R21.1, STAT1.1 (K)
unnamed: C4.1, U1.5 (VCC), U2.5 (VCC), U3.1 (OUT)
unnamed: C10.2, U4.2 (~RESET), U4.3 (3V3OUT), U4.9 (VCCIO)
unnamed: R13.1, U4.1 (USBDM)
unnamed: R12.1, U4.12 (USBDP)
unnamed: C7.2, FB1.1, U4.4 (VCC)
unnamed: R6.2, U8.10 (ICHG)
unnamed: R7.2, U8.8 (ILIM)
unnamed: C2.2, U8.23 (PMID)
unnamed: C34.2, L2.2, U8.19 (SW-1), U8.20 (SW)
unnamed: R3.2, R4.1, U8.11 (TS)
unnamed 40: R5.1, VBus1.1 (K); also elsewhere on the board
PWR: J1.2, R18.1, U1.2 (C)
PWR_EN: R8.2, U4.6 (CBUS0), U8.9 (~CE)
REGN: C35.1, R3.1, U8.22 (REGN)
RXD: J2.10 (RXD), J6.4, U4.7 (TXD/D0)
SCL1: J1.5, J2.5 (SCL)
SDA1: J1.4, J2.3 (SDA)
STAT1: J2.7 (GPIO4), STAT1.2 (A)
TG: J2.40 (GPIO21), R17.1, U2.1 (D), U2.4 (~Q)
TXD: J2.8 (TXD), J6.3, U4.10 (RXD/D1)
VBAT: C36.2, J4.1, U8.13 (BAT-1), U8.14 (BAT)
VBUS: D8.2 (A), FB1.2, J10.A4 (VBUS), J10.A9 (VBUS), J10.B4 (VBUS), J10.B9 (VBUS), R8.1, U5.5 (VBUS), VBus1.2 (A); also elsewhere on the board
VSYS: C30.1, C33.2, L1.1, L2.1, PS1.7 (VIN), R19.2, R20.2, U3.3 (EN), U3.4 (IN), U8.15 (SYS-1), U8.16 (SYS)

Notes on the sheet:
USB-C & DATA PASSTHROUGH
R B W G
External Connections
BATTERY
MCU Connections
Charging
3.3V 50mA
5V Boost converter
SYSTEM
Flip Flop
VOUT 5V 15A
VBAT 2-5V
LEDs



Board: 4 copper layers, 65.0 x 30.0 mm, 73 parts (30 on the bottom side), 53 nets.

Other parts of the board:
BSTAT: LED; LED_0805_2012Metric_Pad1.15x1.40mm_HandSolder
NTF: SW_Push; SW_EVQ-P7J01P
PG: LED; LED_0805_2012Metric_Pad1.15x1.40mm_HandSolder
VBus: LED; LED_0805_2012Metric_Pad1.15x1.40mm_HandSolder
WIFI: SW_Push; SW_EVQ-P7J01P

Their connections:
BAT_PG1: PG.1 (K); also elsewhere on the board
BSTAT1: BSTAT.1 (K); also elsewhere on the board
unnamed 10: PG.2 (A); also elsewhere on the board
unnamed 11: BSTAT.2 (A); also elsewhere on the board
unnamed 15: NTF.2, WIFI.2; also elsewhere on the board
unnamed 16: NTF.1; also elsewhere on the board
unnamed 17: WIFI.1; also elsewhere on the board
unnamed 40: VBus.1 (K); also elsewhere on the board
VBUS: VBus.2 (A); also elsewhere on the board

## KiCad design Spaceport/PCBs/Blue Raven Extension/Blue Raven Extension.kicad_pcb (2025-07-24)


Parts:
H1, H2: MountingHole; MountingHole_3.2mm_M3
J1: Conn_01x06; PinHeader_1x06_P2.54mm_Horizontal
JBAT1: Screw_Terminal_01x06; 3.5mm 6 pos molex screw terminal
SW1: Screw_Terminal_01x06; 3.5mm 6 pos molex screw terminal

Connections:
/3rd: J1.2, JBAT1.2
/4th: J1.1, SW1.6
/Apo: J1.4, JBAT1.4
/Main: J1.3, SW1.4
/SW: JBAT1.5, SW1.2
/Vin: J1.6, JBAT1.1, JBAT1.3, SW1.1, SW1.3, SW1.5
GND: J1.5, JBAT1.6


Board: 2 copper layers, 20.0 x 34.0 mm, 5 parts (0 on the bottom side), 7 nets.

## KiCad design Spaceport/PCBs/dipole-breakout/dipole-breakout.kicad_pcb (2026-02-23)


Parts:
C1: C; C_0805_2012Metric_Pad1.18x1.45mm_HandSolder
J1: Conn_Coaxial; SMA_EDGELAUNCH
J2, J3: Conn_01x01_Pin; Wire Pad
L1: L; L_0805_2012Metric_Pad1.15x1.40mm_HandSolder

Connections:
GND: C1.1, J1.2 (Ext), J2.1, L1.1
unnamed: C1.2, J1.1 (In), J3.1, L1.2


Board: 2 copper layers, 15.8 x 9.0 mm, 7 parts (0 on the bottom side), 2 nets.

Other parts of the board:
H1, H2: MountingHole; MountingHole_2.2mm_M2

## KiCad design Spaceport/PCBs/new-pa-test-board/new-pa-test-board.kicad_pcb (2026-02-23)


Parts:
C1, C2: 27pF; C_0603_1608Metric
C7: 10uF; C_0805_2012Metric
C8: 100pF; C_0603_1608Metric
FB2: 2743019447; L_1806_4516Metric_Pad1.45x1.90mm_HandSolder
J1, J2: Conn_Coaxial; SMA_EDGELAUNCH
J3, J4: Conn_01x03_Pin; PinHeader_1x03_P2.54mm_Vertical
L1: 4.3nH; L_0603_1608Metric
L2: 5.1nH; L_0603_1608Metric
L3: 18nH; L_0805_2012Metric
Q1: AFT05MS004NT1
R1, R2: R; R_0805_2012Metric_Pad1.20x1.40mm_HandSolder

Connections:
GND: C7.2, C8.2, J1.2 (Ext), J2.2 (Ext), J3.2, J4.3, L1.2, L2.2, Q1.3 (S)
unnamed: C1.1, J1.1 (In), L1.1
unnamed: C2.2, J2.1 (In), L2.1
unnamed: C8.1, FB2.1, J4.1, L3.2, R1.1
unnamed: C2.1, L3.1, Q1.1 (D)
unnamed: C1.2, Q1.2 (G), R1.2
VBIAS: J4.2, R2.1
VDD: C7.1, FB2.2, J3.1


Board: 2 copper layers, 28.9 x 16.4 mm, 15 parts (0 on the bottom side), 8 nets.

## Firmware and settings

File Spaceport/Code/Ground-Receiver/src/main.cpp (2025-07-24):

#include <Arduino.h>
#include "RadioMessage.h"
#include "Si4463.h"
#include <Adafruit_SSD1306.h>

#define SCREEN_WIDTH 128 // OLED display width, in pixels
#define SCREEN_HEIGHT 32 // OLED display height, in pixels

#define OLED_RESET -1       // Reset pin # (or -1 if sharing Arduino reset pin)
#define SCREEN_ADDRESS 0x3C ///< See datasheet for Address; 0x3D for 128x64, 0x3C for 128x32
Adafruit_SSD1306 display(SCREEN_WIDTH, SCREEN_HEIGHT, &Wire, OLED_RESET);

static const unsigned char PROGMEM logo_bmp[] =
    {0b00000000, 0b11000000,
     0b00000001, 0b11000000,
     0b00000001, 0b11000000,
     0b00000011, 0b11100000,
     0b11110011, 0b11100000,
     0b11111110, 0b11111000,
     0b01111110, 0b11111111,
     0b00110011, 0b10011111,
     0b00011111, 0b11111100,
     0b00001101, 0b01110000,
     0b00011011, 0b10100000,
     0b00111111, 0b11100000,
     0b00111111, 0b11110000,
     0b01111100, 0b11110000,
     0b01110000, 0b01110000,
     0b00000000, 0b00110000};

#include "422Mc86_4GFSK_500000H.h"
#include "422Mc80_4GFSK_009600H.h"

#define TELEM_DEVICE_ID 3
#define AVIONICS_DEVICE_ID 2
#define PAYLOAD_DEVICE_ID 1

const char avionicsCall[] = "KD3BBD";
const char airbrakeCall[] = "KC3UTM";
const char payloadCall[] = "KQ4TCN";
const char commandCall[] = "KD3BBD"; // TODO: sync with commandConfig object

HardwareSerial *s;

Si4463HardwareConfig hwcfgTelem = {
    MOD_4GFSK,       // modulation
    DR_4_8k,         // data rate
    (uint32_t)430e6, // frequency (Hz)
    POWER_HP_33dBm,  // tx power (127 = ~20dBm)
    192,             // preamble length
    32,              // required received valid preamble
};

Si4463PinConfig pincfgTelem = {
    &SPI, // spi bus to use
    33,   // cs
    39,   // sdn
    34,   // irq
    35,   // gpio0
    36,   // gpio1
    37,   // gpio2
    38,   // gpio3
};

Si4463HardwareConfig hwcfgAvionics = {
    MOD_4GFSK,       // modulation
    DR_250k,         // data rate
    (uint32_t)433e6, // frequency (Hz)
    // (uint32_t)430.6e6, // frequency (Hz)
    POWER_HP_20dBm, // tx power (127 = ~20dBm)
    192,            // preamble length
    32,             // required received valid preamble
};

Si4463PinConfig pincfgAvionics = {
    &SPI, // spi bus to use
    30,   // cs
    29,   // sdn
    24,   // irq
    25,   // gpio0
    26,   // gpio1
    27,   // gpio2
    28,   // gpio3
};

Si4463HardwareConfig hwcfgPayload = {
    MOD_4GFSK,         // modulation
    DR_250k,           // data rate
    (uint32_t)431.3e6, // frequency (Hz)
    POWER_HP_20dBm,    // tx power (127 = ~20dBm)
    192,               // preamble length
    32,                // required received valid preamble
};

Si4463PinConfig pincfgPayload = {
    &SPI, // spi bus to use
    6,    // cs
    5,    // sdn
    0,    // irq
    1,    // gpio0
    2,    // gpio1
    3,    // gpio2
    4,    // gpio3
};

Si4463 radioTelem(hwcfgTelem, pincfgTelem);
Si4463 radioAvionics(hwcfgAvionics, pincfgAvionics);
Si4463 radioPayload(hwcfgPayload, pincfgPayload);

enum InputState
{
  HANDSHAKE,
  COMMAND,
  // add additional states as necessary
  NONE
};

// overall behavior control
bool handshakeSuccess = false;
bool hasDataHeader = false;

// Serial handling control
InputState currState = NONE;

// Serial communication handling
bool foundNewline = false;
int bytesAvail = 0;
char serialBuf[Message::maxSize] = {0};
int serialBufLength = 0;
Message commandMsg;
APRSConfig commandConfig = {"KD3BBD", "ALL", "WIDE1-1", PositionWithoutTimestampWithoutAPRS, '\\', 'M'};
uint16_t commandSize = 0;

// data handling
uint32_t timerMetrics = millis();
Message m;

// telemetry
APRSTelem telem;
GSData avionicsData(APRSTelem::type, 1, TELEM_DEVICE_ID);
bool hasAvionicsTelem = false;
GSData airbrakeData(APRSTelem::type, 2, TELEM_DEVICE_ID);
bool hasAirbrakeTelem = false;
GSData payloadData(APRSTelem::type, 3, TELEM_DEVICE_ID);
bool hasPayloadTelem = false;

// video
Message avionicsVideoMessage;
VideoData avionicsVideo;
GSData avionicsVideoData(VideoData::type, 5, AVIONICS_DEVICE_ID);
bool hasAvionicsVideo = false;
Message payloadVideoMessage;
VideoData payloadVideo;
GSData payloadVideoData(VideoData::type, 6, PAYLOAD_DEVICE_ID);
bool hasPayloadVideo = false;

// sample metrics implementation
Message metricsMessage;
Metrics telemMetrics(TELEM_DEVICE_ID);
Metrics avionicsVideoMetrics(AVIONICS_DEVICE_ID);
Metrics payloadVideoMetrics(PAYLOAD_DEVICE_ID);
GSData metricsGSData(Metrics::type, 4, TELEM_DEVICE_ID);

void log(const char *str1, const char *str2 = "", const char *str3 = "")
{
  Serial5.print(str1);
  Serial5.print(str2);
  Serial5.print(str3);
  Serial5.write("\n");
}

void setup()
{
  // Modify baud rate to match desired bitrate
  Serial.begin(1000000);
  Serial5.begin(115200);

  s = (HardwareSerial *)&Serial;

  if (CrashReport)
  {
    Serial5.println(CrashReport);
    while (1)
      ;
  }
  // adding the ground station OLED stuff
  if (!display.begin(SSD1306_SWITCHCAPVCC, SCREEN_ADDRESS))
  {
    Serial.println(F("SSD1306 allocation failed"));
    for (;;)
      ; // Don't proceed, loop forever
  }

  // Show initial display buffer contents on the screen --
  // the library initializes this with an Adafruit splash screen.
  display.display();
  delay(2000); // Pause for 2 seconds

  // Clear the buffer
  display.clearDisplay();
  delay(2000);
  // display.display() is NOT necessary after every single drawing command,
  // unless that's what you want...rather, you can batch up a bunch of
  // drawing operations and then update the screen all at once by calling
  // display.display(). These examples demonstrate both approaches...

  // Invert and restore display, pausing in-between
  display.invertDisplay(true);
  delay(1000);
  display.invertDisplay(false);
  delay(1000);

  // if (!radioTelem.begin(CONFIG_422Mc80_4GFSK_009600H, sizeof(CONFIG_422Mc80_4GFSK_009600H)))
  // {
  //   log("Error: telemetry radio failed to begin");
  //   while (1)
  //     ;
  // }

  if (!radioAvionics.begin(CONFIG_422Mc86_4GFSK_500000H, sizeof(CONFIG_422Mc86_4GFSK_500000H)))
  {
    log("Error: Avionics video radio failed to begin");
    while (1)
      ;
  }

  // if (!radioPayload.begin(CONFIG_422Mc86_4GFSK_500000H, sizeof(CONFIG_422Mc86_4GFSK_500000H)))
  // {
  //   log("Error: Payload video radio failed to begin");
  //   while (1)
  //     ;
  // }

  log("Initialization complete");
  log("Avionics callsign is: ", avionicsCall);
  log("Airbrake callsign is: ", airbrakeCall);
  log("Payload callsign is: ", payloadCall);
  log("Command calsign is: ", commandCall);
}

void loop()
{
  // adding the OLED stuff
  char s[50];

  display.clearDisplay();
  // all the settings for the text
  display.setCursor(0, 0);
  display.setFont(NULL);
  display.setTextColor(SSD1306_WHITE);
  display.startWrite();
  display.setTextSize(1);
  display.setTextWrap(false);

  // latitude double addition
  double lf = -0.2;
  snprintf(s, sizeof(s), "Lat: %lf \n", lf);
  display.print(s);

  // longtitude double addition
  double lf2 = -0.5;
  snprintf(s, sizeof(s), "Long: %lf", lf2);
  display.setCursor(0, 8);
  display.print(s);

  // RSSI integer addition
  int lf3 = 35;
  snprintf(s, sizeof(s), "RSSI: %d", lf3);
  display.setCursor(0, 17);
  display.print(s);

  // displaying avionics, airbrake, and payload warning signals
  display.setCursor(24, 25);
  display.print("AVI, AIR, PAY");
  // optional delay
  delay(100);
  // DISPLAY.DISPLAY() IS NEEDED!!
  display.display();

  // optional delay
  delay(2000);

  if (((bytesAvail = Serial5.available()) > 0))
  {
    // check if a command is being sent
    if (currState == NONE)
    {
      log("buf");
      for (int i = 0; i < bytesAvail; i++)
      {
        char c = s->read();
        if (c == '\n')
        {
          serialBuf[serialBufLength] = 0;
          foundNewline = true;
          break;
        }
        if (c != '\0')
        {
          serialBuf[serialBufLength] = c;
          serialBufLength++;
          if (serialBufLength >= (int)sizeof(serialBuf))
            break;
        }
      }
      bytesAvail = s->available();

      if (foundNewline)
      {
        log("newline command ", serialBuf);
        if (strcmp(serialBuf, "handshake") == 0)
        {
          log("Starting handshake");
          // begin the handshake
          handshakeSuccess = false;
          currState = HANDSHAKE;
        }
        else if (strcmp(serialBuf, "handshake succeeded") == 0)
        {
          log("Successful handshake");
          // the handshake was successful
          handshakeSuccess = true;
          // we will start sending data, so set up metrics
          telemMetrics.setInitialTime(millis());
        }
        else if (strcmp(serialBuf, "handshake failed") == 0)
        {
          log("Failed handshake");
          // the handshake was not successful
          handshakeSuccess = false;
        }
        else if (strcmp(serialBuf, "command") == 0)
        {
          log("Ready for radio command");
          // the next text will be a radio command
          commandMsg.clear();
          currState = COMMAND;
        }
        // add additional commands as required

        // reset serial buffer
        memset(serialBuf, 0, sizeof(serialBuf));
        serialBufLength = 0;
        foundNewline = false;
      }
    }

    // complete the handshake
    if (currState == HANDSHAKE)
    {
      for (int i = 0; i < bytesAvail; i++)
      {
        char c = s->read();
        log("read:");
        // skip odd characters that accidently get added
        if (c != 0xff && c != 0)
        {
          s->write(c);
          if (c == '\n')
          {
            log("newline handshake");
            foundNewline = true;
            break;
          }
        }
      }
      bytesAvail = s->available();

      if (foundNewline)
      {
        foundNewline = false;
        currState = NONE;
      }
    }

    // receive the radio command
    if (currState == COMMAND)
    {
      // read into serial buffer
      for (int i = 0; i < bytesAvail; i++)
      {
        commandMsg.append(s->read());
        if (commandMsg.size >= Message::maxSize)
          break;
      }
      bytesAvail = s->available();

      if (commandMsg.size >= GSData::headerLen)
      {
        // we can decode the header
        uint8_t type, id, deviceId = 0;
        GSData::decodeHeader(commandMsg.buf, type, id, deviceId, commandSize);
        if (type != APRSCmd::type || id == 0 || commandSize == 0)
        {
          // this is not an APRSCmd, ignore it
          currState = NONE;
        }
      }

      if (commandMsg.size - GSData::headerLen > commandSize && commandSize != 0)
      {
        // remove the extra bytes and put them in the serial buffer in case they are part of a different message
        uint16_t removed = (commandMsg.size - GSData::headerLen) - commandSize;
        commandMsg.pop((uint8_t *)serialBuf, removed);
        serialBufLength += removed;
      }
      if (commandMsg.size - GSData::headerLen == commandSize && commandSize != 0)
      {
        // we have the full command, so decode it
        GSData multiplexedCommand;
        commandMsg.decode(&multiplexedCommand);
        // send the actual command data
        commandMsg.clear();
        commandMsg.fill(multiplexedCommand.buf, multiplexedCommand.size);
        APRSCmd cmd;
        commandMsg.decode(&cmd);
        cmd.config = commandConfig;
        commandMsg.encode(&cmd);
        commandMsg.write(Serial); // TODO: log for now, need to send to radio
        // we are now finished handling the radio command on the Serial side
        currState = NONE;
      }
    }

    // add additional command handling here
  }

  // radio
  // if (handshakeSuccess && radioTelem.avail())
  // {
  //   // get the message
  //   radioTelem.receive(telem);
  //   // re-encode it to be multiplexed
  //   m.encode(&telem);
  //   // update metrics
  //   telemMetrics.update(m.size, millis(), radioTelem.RSSI());
  //   // set the flag to transmit data
  //   if (strcmp(telem.config.callsign, avionicsCall) == 0)
  //     hasAvionicsTelem = true;
  //   if (strcmp(telem.config.callsign, airbrakeCall) == 0)
  //     hasAirbrakeTelem = true;
  //   if (strcmp(telem.config.callsign, payloadCall) == 0)
  //     hasPayloadTelem = true;
  // }

  if (handshakeSuccess && radioAvionics.avail())
  {
    // get the message
    avionicsVideo.size = radioAvionics.readRXBuf(avionicsVideo.data, radioAvionics.length);
    // re-encode it to be multiplexed
    avionicsVideoMessage.encode(&avionicsVideo);
    // update metrics
    avionicsVideoMetrics.update(avionicsVideoMessage.size, millis(), radioAvionics.RSSI());
    // set the flag to transmit data
    hasAvionicsVideo = true;
    // reset avail flag
    radioAvionics.available = false;
  }

  // if (handshakeSuccess && radioPayload.avail())
  // {
  //   // get the message
  //   payloadVideo.size = radioPayload.readRXBuf(payloadVideo.data, VideoData::maxSize);
  //   // re-encode it to be multiplexed
  //   payloadVideoMessage.encode(&payloadVideo);
  //   // update metrics
  //   payloadVideoMetrics.update(payloadVideoMessage.size, millis(), radioPayload.RSSI());
  //   // set the flag to transmit data
  //   hasPayloadVideo = true;
  //   // reset avail flag
  //   radioPayload.available = false
  // }

  if (handshakeSuccess)
  {
    // output goes here
    if (hasAvionicsTelem)
    {
      // fill GSData with message
      avionicsData.fill(m.buf, m.size);
      // encode for multplexing
      m.encode(&avionicsData);
      // write
      log("Avionics data: ", (const char *)m.buf);
      s->write(m.buf, m.size);
      // reset flag
      hasAvionicsTelem = false;
    }

    if (hasAirbrakeTelem)
    {
      // fill GSData with message
      airbrakeData.fill(m.buf, m.size);
      // encode for multplexing
      m.encode(&airbrakeData);
      // write
      log("Airbrake data: ", (const char *)m.buf);
      s->write(m.buf, m.size);
      // reset flag
      hasAirbrakeTelem = false;
    }

    if (hasPayloadTelem)
    {
      // fill GSData with message
      payloadData.fill(m.buf, m.size);
      // encode for multplexing
      m.encode(&payloadData);
      // write
      log("Payload data: ", (const char *)m.buf);
      s->write(m.buf, m.size);
      // reset flag
      hasPayloadTelem = false;
    }

    if (hasAvionicsVideo)
    {
      if (avionicsVideoMessage.size > GSData::maxSize)
      {
        // Assume it is no more than double the maxSize
        // Need to split into 255 bytes chunks (assume it is an integer multiple of 255)
        int chunks = avionicsVideo.size / 255;
        int chunksFirstHalf = chunks - chunks / 2;
        int chunksSecondHalf = chunks - chunksFirstHalf;

        // fill GSData with first half of message
        avionicsVideoData.fill(avionicsVideo.data, chunksFirstHalf * 255);
        // encode for multplexing
        avionicsVideoMessage.encode(&avionicsVideoData);
        // write
        s->write(avionicsVideoMessage.buf, avionicsVideoMessage.size);
        // fill GSData with second half of message
        avionicsVideoData.fill(avionicsVideo.data + (chunksFirstHalf * 255), chunksSecondHalf * 255);
        // encode for multplexing
        avionicsVideoMessage.encode(&avionicsVideoData);
        // write
        s->write(avionicsVideoMessage.buf, avionicsVideoMessage.size);
        // reset flag
        hasAvionicsVideo = false;
      }
      else
      {
        // fill GSData with message
        avionicsVideoData.fill(avionicsVideoMessage.buf, avionicsVideoMessage.size);
        // encode for multplexing
        avionicsVideoMessage.encode(&avionicsVideoData);
        // write
        s->write(avionicsVideoMessage.buf, avionicsVideoMessage.size);
        // reset flag
        hasAvionicsVideo = false;
      }
    }

    if (hasPayloadVideo)
    {
      if (payloadVideoMessage.size > GSData::maxSize)
      {
        // Assume it is no more than double the maxSize
        // Need to split into 255 bytes chunks (assume it is an integer multiple of 255)
        int chunks = payloadVideoMessage.size / 255;
        int chunksFirstHalf = chunks - chunks / 2;
        int chunksSecondHalf = chunks - chunksFirstHalf;

        // fill GSData with first half of message
        payloadVideoData.fill(payloadVideoMessage.buf, chunksFirstHalf * 255);
        // encode for multplexing
        payloadVideoMessage.encode(&payloadVideoData);
        // write
        s->write(payloadVideoMessage.buf, payloadVideoMessage.size);
        // fill GSData with second half of message
        payloadVideoData.fill(payloadVideoMessage.buf + (chunksFirstHalf * 255), chunksSecondHalf * 255);
        // encode for multplexing
        payloadVideoMessage.encode(&payloadVideoData);
        // write
        s->write(payloadVideoMessage.buf, payloadVideoMessage.size);
        // reset flag
        hasPayloadVideo = false;
      }
      else
      {
        // fill GSData with message
        payloadVideoData.fill(payloadVideoMessage.buf, payloadVideoMessage.size);
        // encode for multplexing
        payloadVideoMessage.encode(&payloadVideoData);
        // write
        s->write(payloadVideoMessage.buf, payloadVideoMessage.size);
        // reset flag
        hasPayloadVideo = false;
      }
    }

    if (millis() - timerMetrics > 1000)
    {
      timerMetrics = millis();
      metricsMessage.encode(&telemMetrics);
      metricsGSData.fill(metricsMessage.buf, metricsMessage.size);
      metricsMessage.encode(&metricsGSData);
      s->write(metricsMessage.buf, metricsMessage.size);
      metricsMessage.encode(&avionicsVideoMetrics);
      metricsGSData.fill(metricsMessage.buf, metricsMessage.size);
      metricsMessage.encode(&metricsGSData);
      s->write(metricsMessage.buf, metricsMessage.size);
      metricsMessage.encode(&payloadVideoMetrics);
      metricsGSData.fill(metricsMessage.buf, metricsMessage.size);
      metricsMessage.encode(&metricsGSData);
      s->write(metricsMessage.buf, metricsMessage.size);
    }
  }

  // radioTelem.update();
  radioAvionics.update();
  // radioPayload.update();
}

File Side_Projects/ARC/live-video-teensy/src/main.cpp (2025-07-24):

#include <Arduino.h>
#include "Wire.h"

#include "rs.h"

#include "Si4463.h"
#include "MockRadio.h"
#include "RadioMessage.h"

// radio config header
#include "422Mc86_4GFSK_500000H.h"

// pin definitions
#define BUZZER 33
#define LED 32

// data flow constants
#define MSG_CHUNK_SIZE 255
#define MSG_SIZE (MSG_CHUNK_SIZE * 32)              // 8160 (should be * 32)
#define MSG_CHUNK_DATA_SIZE (MSG_CHUNK_SIZE - NPAR) // 245
#define MSG_THRESH (MSG_SIZE)

// Serial communication with Pi
uint8_t buf[MSG_SIZE * 3];
uint8_t codeword[255];

// radio variables
bool hasTransmission = false;
bool firstTX = true;

int top = 0;
int toSend = 0;
int sent = 0;
int bytesThisMessage = 0;

uint32_t txTimeout = millis();

// testing
uint32_t debugTimer = millis();
int debugCounter = 0;
uint32_t debugLoopTime = 0;
GSData vHeader(VideoData::type, 3, 1);
uint8_t vHeaderBuf[GSData::headerLen] = {};
// end testing

// Reed solomon
RS rs;
bool disableRS = true;

// radio config
APRSConfig aprscfg = {"KC3UTM", "ALL", "WIDE1-1", TextMessage, '\\', 'M'};

Si4463HardwareConfig hwcfg = {
    MOD_4GFSK,        // modulation
    DR_250k,          // data rate
    (uint32_t)433e6,  // frequency (Hz)
    POWER_COTS_30dBm, // tx power
    192,              // preamble length
    32,               // required received valid preamble
};

Si4463PinConfig pincfg = {
    &SPI, // spi bus to use
    10,   // cs
    2,    // sdn
    7,    // irq
    6,    // gpio0
    5,    // gpio1
    4,    // gpio2
    3,    // gpio3
};

Si4463 radio(hwcfg, pincfg);

// MockHardwareConfig hwcfg = {
//     500000};

// MockPinConfig pincfg = {
//     &Serial6};

// MockRadio radio(hwcfg, pincfg);

void beep(int time)
{
  digitalWrite(BUZZER, HIGH);
  delay(time);
  digitalWrite(BUZZER, LOW);
  delay(time);
}

void blink(int time)
{
  digitalWrite(LED, HIGH);
  delay(time);
  digitalWrite(LED, LOW);
  delay(time);
}

void pattern(void (*f)(int), int time, int loops)
{
  for (int i = 0; i < loops; i++)
  {
    f(time);
  }
}

char GSMHeader[GSData::gsmHeaderSize] = {};

void setup()
{
  Serial.begin(250000);

  // serial
  Serial1.begin(500000);
  // i2c
  // Wire.begin(0x01);

  // setup buzzer and led
  pinMode(BUZZER, OUTPUT);
  pinMode(LED, OUTPUT);
  digitalWrite(BUZZER, LOW);
  digitalWrite(LED, LOW);

  if (CrashReport)
    Serial.println(CrashReport);

  if (!radio.begin(CONFIG_422Mc86_4GFSK_500000H, sizeof(CONFIG_422Mc86_4GFSK_500000H)))
  // if (!radio.begin())
  {
    Serial.println("Transmitter failed to begin");
    Serial.flush();
    beep(1000);
    while (1)
      ;
  }

  if (MSG_THRESH > MSG_SIZE)
  {
    Serial.println("Sending threshold greater than message size!");
    Serial.flush();
    while (1)
      ;
  }

  // using buf because just need a valid arr
  // only need to extract the header
  // vHeader.fill(buf, MSG_SIZE);
  // vHeader.encode(buf, MSG_SIZE);
  // this header should be valid for every packet
  // memcpy(vHeaderBuf, buf, GSData::headerLen);
  // reset buf for good measure
  // memset(buf, 0, MSG_SIZE);

  // write GSM header
  // GSData::encodeGSMHeader(GSMHeader, GSData::gsmHeaderSize, 400000);

  Serial.print("Reed solomon is: ");
  Serial.println(disableRS ? "DISABLED" : "ENABLED");
  Serial.print("Using RS-");
  Serial.print(MSG_CHUNK_DATA_SIZE);
  Serial.print(",");
  Serial.println(MSG_CHUNK_SIZE);
  Serial.print("Message size is: ");
  Serial.print(MSG_SIZE);
  Serial.println(" bytes");
  Serial.print("Threshold is: ");
  Serial.print(MSG_THRESH);
  Serial.println(" bytes");
  Serial.println("Setup complete");
  pattern(beep, 100, 3);
}

void loop()
{
  // debugTimer = micros();
  // reading from Raspi
  while (Serial1.available() > 0 && top + NPAR + 1 < MSG_SIZE * 3)
  // while (Wire.available() > 0 && top + NPAR + 1 < MSG_SIZE * 3)
  {
    txTimeout = millis();
    buf[top] = Serial1.read();
    // buf[top] = Wire.read();
    top++;

    if (bytesThisMessage + toSend < MSG_SIZE && hasTransmission)
    {
      toSend++;
    }

    // if (top == MSG_SIZE + 3)
    // {
    //   Serial.println();
    //   Serial.println("Read: Sniffing beginning of next packet: ");
    //   Serial.print(top);
    //   Serial.print(" ");
    //   Serial.println(toSend);
    //   Serial.print(buf[bytesThisMessage], HEX);
    //   Serial.print(" ");
    //   Serial.print(buf[bytesThisMessage + 1], HEX);
    //   Serial.print(" ");
    //   Serial.println(buf[bytesThisMessage + 2], HEX);
    // }

    // add RS once we have MSG_CHUNK_SIZE bytes
    if (top != 0 && ((top - (MSG_CHUNK_SIZE * (top / MSG_CHUNK_SIZE))) % MSG_CHUNK_DATA_SIZE) == 0 && !disableRS)
    {
      // (top - (MSG_CHUNK_SIZE * (top / MSG_CHUNK_SIZE))) the number of bytes not part of an already coded message
      // Serial.println("RS");
      // Serial.print("top ");
      // Serial.print(top);
      // Serial.print("\t");
      // Serial.print(MSG_CHUNK_DATA_SIZE);
      // Serial.print("\ttoSend ");
      // Serial.print(toSend);
      // Serial.print("\thasTX ");
      // Serial.println(hasTransmission);
      rs.encode_data(buf + (top - MSG_CHUNK_DATA_SIZE), MSG_CHUNK_DATA_SIZE, codeword);
      // for (int i = 0; i < MSG_CHUNK_DATA_SIZE; i++)
      // {
      //   Serial.print((buf + (top - MSG_CHUNK_DATA_SIZE))[i], HEX);
      //   Serial.print(" ");
      // }
      // Serial.println();
      // for (int i = 0; i < sizeof(codeword); i++)
      // {
      //   Serial.print(codeword[i], HEX);
      //   Serial.print(" ");
      // }
      // Serial.println();
      memcpy(buf + (top - MSG_CHUNK_DATA_SIZE), codeword, sizeof(codeword));
      top += NPAR;
      if (bytesThisMessage + toSend + NPAR <= MSG_SIZE && hasTransmission)
      {
        toSend += NPAR;
      }
    }
  }

  if (top >= MSG_SIZE * 3)
  {
    Serial.print("Buffer overrun!\ttop ");
    Serial.println(top);
  }
  if (toSend >= MSG_SIZE)
  {
    Serial.print("Sending too many bytes!\ttoSend ");
    Serial.println(toSend);
  }

  // Refill fifo here
  if (hasTransmission && toSend > 0)
  {
    uint16_t added = radio.writeTXBuf(buf + bytesThisMessage, toSend);
    if (added != toSend)
    {
      Serial.println("");
      Serial.println("E ");
      Serial.print(added);
      Serial.print(" ");
      Serial.println(toSend);
      while (1)
        ;
    }
    // Serial.write(buf + bytesThisMessage, toSend);
    sent = toSend;
    bytesThisMessage += toSend;
    toSend = 0;
  }

  // Start a new transmission
  if ((top >= MSG_THRESH || (millis() - txTimeout > 1000 && top > 0 && !firstTX)) && !hasTransmission)
  {
    uint32_t timer = micros();
    // turn on led
    digitalWrite(LED, HIGH);
    // TODO: remove temp
    // if (firstTX)
    //   Serial.write(GSMHeader, GSData::gsmHeaderSize);
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

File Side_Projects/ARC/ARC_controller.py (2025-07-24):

#!/bin/python -u

import RPi.GPIO as GPIO
from datetime import datetime
import subprocess
import time
import os
import re
import atexit
import signal
import select

# GPIO Configuration
CMD_PIN = 6    # Input pin (from Teensy)
INTERFACE_PIN = 12 # Input pin (external source)
WIFI_RST_PIN = 13 # Input pin (external source)
# RESP_PIN = 5   # Output pin (to Teensy)
GPIO.setmode(GPIO.BCM)
GPIO.setup(CMD_PIN, GPIO.IN, pull_up_down=GPIO.PUD_DOWN)
GPIO.setup(INTERFACE_PIN, GPIO.IN, pull_up_down=GPIO.PUD_DOWN)
GPIO.setup(WIFI_RST_PIN, GPIO.IN, pull_up_down=GPIO.PUD_DOWN)
# GPIO.setup(RESP_PIN, GPIO.OUT, initial=GPIO.HIGH)
unixTime = int((datetime.now() - datetime(1970, 1, 1)).total_seconds())

logFile = open(os.path.expanduser("~/ARC_log/" + str(unixTime) + "_log.txt"), "w")

# handy logging functions
def logPrintln(s):
    s = "[" + str(datetime.now().time()) + "] " + s
    print(s)
    logFile.write(s + "\n")
    logFile.flush()


logPrintln("ARC Controller startup complete")

# process control
video = False
live = False
interface = False
exited = False

# subprocesses
rpicam_process = None
av1_process = None
transmit_process = None
interface_process = None
interface_select = None
stream_process = None

# command strings
command_rpicam = "rpicam-vid -t 300000 --codec yuv420 --width 1280 --height 720 --framerate 30 --no-raw -o -"
command_av1 = "aomenc -w 1280 -h 720 --profile=0 --kf-max-dist=300 --end-usage=cbr --min-q=1 --max-q=38 " \
"--undershoot-pct=100 --overshoot-pct=25 --buf-sz=20 --buf-initial-sz=10 --buf-optimal-sz=10 --max-intra-rate=600 " \
"--passes=1 --lag-in-frames=0 --error-resilient=0 --tile-columns=1 --tile-rows=3 --aq-mode=2 --enable-obmc=0 " \
"--enable-global-motion=1 --enable-warped-motion=0 --deltaq-mode=0 --enable-tpl-model=1 --mode-cost-upd-freq=2 " \
"--coeff-cost-upd-freq=2 --enable-ref-frame-mvs=0 --mv-cost-upd-freq=3 --enable-order-hint=0 --drop-frame=0 " \
"--resize-mode=3 --cpu-used=5 --rt --usage=1 --threads=3 --obu --target-bitrate=450 --fps=30/1 - -o "
command_transmit = "teensy-interface"
command_interface = "node ARC_utilities/app.js"
# assumes username is the same as hostname, WILL NOT WORK OTHERWISE
command_stream = "ffmpeg -f rawvideo -s 1280x720 -r 30 -i - -listen 1 -preset ultrafast -tune zerolatency -f mp4 -pix_fmt yuv420p -x264-params keyint=1 -g 1 -movflags +faststart+frag_keyframe+empty_moov -r 30 http://" + str(os.environ["LOGNAME"]) + ".local:7999"

def start_recording():
    global rpicam_process
    global av1_process
    global command_rpicam
    global command_av1

    rpicam_process = subprocess.Popen(command_rpicam.split(" "),
                                    stdout=subprocess.PIPE)
    av1_process = subprocess.Popen((command_av1 + os.path.expanduser("~/ARC_video/" + str(unixTime) + "_video.av1")).split(" "),
                                    stdin=rpicam_process.stdout)

def start_transmitting():
    global rpicam_process
    global av1_process
    global transmit_process
    global command_rpicam
    global command_av1
    global command_transmit

    rpicam_process = subprocess.Popen(command_rpicam.split(" "),
                                    stdout=subprocess.PIPE)
    av1_process = subprocess.Popen((command_av1 + "-").split(" "),
                                    stdin=rpicam_process.stdout, stdout=subprocess.PIPE)
    transmit_process = subprocess.Popen(command_transmit.split(" "), stdin=av1_process.stdout)

def start_streaming():
    global rpicam_process
    global stream_process
    global command_rpicam
    global command_stream

    rpicam_process = subprocess.Popen(command_rpicam.split(" "),
                                    stdout=subprocess.PIPE)
    stream_process = subprocess.Popen(command_stream.split(" "), stdin=rpicam_process.stdout)

def stop_video():
    global rpicam_process
    global av1_process
    global transmit_process
    global stream_process

    if rpicam_process:
        rpicam_process.kill()
        rpicam_process.wait()
        rpicam_process = None
    if av1_process:
        av1_process.kill()
        av1_process.wait()
        av1_process = None
    if transmit_process:
        transmit_process.kill()
        transmit_process.wait()
        transmit_process = None
    if stream_process:
        stream_process.kill()
        stream_process.wait()
        stream_process = None

def video_callback(channel):
    global video
    cmd_state = GPIO.input(CMD_PIN)

    if cmd_state == GPIO.HIGH and not video:
        # Start recording
        if not live:
            start_recording()
        if live:
            start_transmitting()
        video = True
        # GPIO.output(RESP_PIN, GPIO.LOW)
        logPrintln("Recording started")

    elif cmd_state == GPIO.LOW and video:
        # Stop recording
        stop_video()
        video = False
        # GPIO.output(RESP_PIN, GPIO.HIGH)
        logPrintln("Recording stopped")

def start_interface():
    global interface_process
    global command_interface
    global interface_select

    interface_process = subprocess.Popen(command_interface.split(" "), stdout=subprocess.PIPE)
    interface_select = select.poll()
    interface_select.register(interface_process.stdout, select.POLLIN)

# string to indicate a command from the interface
cmd_trigger = "PYCMD"
# separator between trigger and command
cmd_sep = r"\|"
cmd_regex = cmd_trigger + cmd_sep + r".+"
#print(cmd_regex)
# list of possible commands and their corresponding callbacks
cmd_list = ["start recording", "start transmitting", "start streaming", "stop video"]
cmd_callbacks = [start_recording, start_transmitting, start_streaming, stop_video]

def process_interface():
    global interface_process
    global cmd_trigger
    global cmd_sep
    global cmd_list
    global cmd_callbacks
    global interface_select

    # get a line
    if interface_select.poll(0):
        line = interface_process.stdout.readline()
        if line:
            # check for cmd_trigger and sep
            m = re.search(cmd_regex, line.decode('UTF-8'))
            if m:
                # if match get command part (after sep character)
                cmd = re.split(cmd_sep, m.group())[1].strip()
                # find correct callback
                for i in range(len(cmd_list)):
                    if cmd_list[i] == cmd:
                        logPrintln("Running command " + str(cmd))
                        # all functions return None except the "stop interface callback"
                        if cmd_callbacks[i]():
                            return False
    return True

def stop_interface():
    global interface_process
    if interface_process:
        interface_process.kill()
        interface_process.wait()
        interface_process = None
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

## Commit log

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2023-11-17 Add files via upload
    Updated routing that fixes error with VCC_RF (it should have been closed in the schematic).
    [GPS.kicad_pcb, GPS.kicad_sch]
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2023-11-28 Rerouted with new pin assignment on antenna footprint
    Left GND pins open for ground plane.
    [GPS.kicad_sch]
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2024-01-17 fix some TODOs from removing Arduino dependencies
    [RFM69HCW.cpp]
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2024-01-19 radio code bug fixes
    [RFM69HCW.cpp]
2024-01-19 more radio code bug fixes
    [RFM69HCW.cpp]
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2024-02-01 Created Avionics State
    Also fixed sensor updates
2024-02-04 a few more radio code bug fixes
    [RFM69HCW.cpp]
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2024-02-14 Didn't stage changes
2024-02-14 Fixed unified board
    [Unified_Board.kicad_pcb, Unified_Board.kicad_sch]
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2024-02-15 Fixed unified board capacitors and LED wiring
    [Unified_Board-B_Cu.gbr, Unified_Board-B_Mask.gbr, Unified_Board-B_Paste.gbr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]
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2024-02-17 Working State.cpp
    Created new Teensy Env to use for test builds.
    Tested and adjusted all classes to fix memory leaks
    Moved tests to folder under Src
    Verified working State.cpp using the fake_data.csv and test_results.csv
    [fake_data.csv, test_results.csv]
2024-02-19 a few fixes to the radio code, added reset
    [RFM69HCW.cpp]
2024-02-22 Numerous bugfixes to RecordData
    Debugging artifacts remain.
    [fake_data.csv, test_results.csv]
2024-02-22 Multiple changes and fixes:
    - Dynamically allocated csv slots based on the number of sensors.
    - RecordData now expects an int for the stage identifier
    - Re-introduced updateSensors() in the state class
    [main.cpp]
2024-02-22 Footprints
    beginning phase, found footprints, schematics, and some random extra detail added
    [Ground Reciever.kicad_pcb, Ground Reciever.kicad_sch]
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2024-02-23 rx and tx working, encode and decode still broken
    [RFM69HCW.cpp, main.cpp]
2024-02-23 Pin connections
    Yes, SCK, GND, MISO, MOSI
    No, INT, RST, VCC, and 1 CS
    [Ground Reciever.kicad_pcb, Ground Reciever.kicad_sch]
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2024-02-26 Removed dynamic allocation and fixed some bugs
    [RFM69HCW.cpp]
2024-02-26 Rearranged files and integrated into State.h.
    Known issues:
    - heap arrays in State::initKF are never deleted
    - Not having an IMU would break parts of the filter, and by exention our stage detection code.
    Other recommendations:
    - Move the kf to a class based system
    - Allow the kf to take in double pointers so that state variables can be passed in and out directly
    - Add a Sensor.Update() to make the call to the sensor and store the results locally. Most currently mix updating and fetching data into one method.
2024-02-26 In progress. Multiple errors.
    [main.cpp]
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2024-02-27 final fixes, cleaning up, and updating tests
    [RFM69HCW.cpp, main.cpp]
2024-02-27 Moved csvHeader printing to sd card init.
    Also fixed the TEST_STATE to work with new sytem
    [main.cpp]
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2024-02-27 Minor fixes that should have already come from main.
    [main.cpp]
2024-02-28 Numerous bug fixes.
    - RecordData now dumps when stage is udpated.
    - Added slightly more robustness to SD card init.
    - Separated SD card csv header from init to help with data logging.
    - Re-ordered main setup() to fit new requirements for data logging.
    - Fixed CSV header being truncated.
    [main.cpp]
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2024-02-28 Massive amounts of bugfixes. Appears to be working.
    [test_results.csv]
2024-02-28 more fixes
    [test_results.csv]
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2024-02-29 final additions
    updated schematic to reflect the new add-ons and assigned proper footprints.
    added leds and resistor to indicate proper transmissions of data and one for power on the teensy.
    [Ground Reciever.kicad_pcb, Ground Reciever.kicad_sch]
2024-02-29 Merged and Squashed main to add radio fixes.
    Removed refrence to RadioHead in the libdeps of the teensy. It causes conflicts with an existing earlier version of the RadioHead library.
    [SRAD eBay sled v1.SLDPRT]
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2024-03-01 Basic fix for matirx mult memory leak and fixed units in GPS and baro.
    [test_results.csv]
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2024-03-01 final final
    cleaned up lines, swapped led locations, shrank overall pcb size a little
    [Ground Reciever.kicad_pcb, Ground Reciever.kicad_sch]
2024-03-01 eBay Assembly
    In preparation for the March 2024 launch, created an eBay to store electronics for live video as well as other avionics tasks.
    [Battery Pack.SLDPRT, COTS Bottom Battery Panel.SLDPRT, COTS Middle Battery Panel.SLDPRT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]
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2024-03-01 band-aid i2c error fix
    [main.cpp]
2024-03-02 Fixes to radio code, tessting, and files
    [test_results.csv]
2024-03-02 Fix to GPS time of day
    [test_results.csv]
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2024-03-06 Went back and changed as many remaining variables as I could find.
    Apparently I missed some of the radio code entirely
    [RFM69HCW.cpp]
2024-03-24 Fixed traces & gerbers
    [Ground Reciever-B_Cu.gbr, Ground Reciever-B_Mask.gbr, Ground Reciever-B_Paste.gbr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]
2024-04-02 add python script to launch libcamera and encoder
    replaces calling a bash script like in start_on_gpio.py
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2024-04-05 radio code bug fixes, preparing for long packets
    [RFM69HCW.cpp]
2024-04-05 Small bug fixes from merge
    [RFM69HCW.cpp]
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2024-04-06 raspi and radio fixes
    [RFM69HCW.cpp, main.cpp]
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2024-04-09 Attempts to fix crashing
    [test_results.csv]
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2024-04-16 missed a couple things
2024-04-17 many changes, not working but no longer crashing
    [test_results.csv]
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2024-05-17 Absolutely massive rework of the radio system for two way radios
    [RFM69HCW.cpp, main.cpp]
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2024-05-20 PCB gerbers and LVPD fix
    [Ground Reciever.kicad_sch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]
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2024-06-08 Revert "nothing is working"
    This reverts commit d5ee48ce016b93a603fbf4bd8013ace73675d4ce.
    [main.cpp]
2024-06-19 completely fixed 100 percent
    except not haha gotcha
    [main.cpp]
2024-06-23 Final compilation error fixes
    [main.cpp]
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2024-07-11 first pass done
    It's actually the second pass, as I had the wrong MCU the first time.
    [Barometer.kicad_sch, GPS.kicad_sch, IMU.kicad_sch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]
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2024-09-04 Updated to TEENSY 4.1 Hight with SMA
    Added SMA female instead of patch antenna. Hight adjusted to hight of Teensy.
    Issue: PCB boarder not defined
    [BMI088.step, Barometer.kicad_sch, DPS310XTSA1.step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]
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2024-09-10 Remove Packet and fix an issue with Message
    [main.cpp]
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2024-09-11 Prevent git from cloning the Ground Station by default
2024-09-14 V1
    V1 of MAX-M10S Breakout PCB for testing with VNA.
    Issue - Need to figure out how to make a ground plane.
    [MAX-M10S SMA Breakout.kicad_pcb, MAX-M10S SMA Breakout.kicad_sch]
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2024-09-18 Finished basic schematic
    Made schematic with Teensy 4.1 and several connectors for I²C, UART, and SPI.
    [mcu-board.kicad_sch]
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2024-09-22 Fixed Logger build issues
    [main.cpp]
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2024-09-24 Added mounting holes and labels
    Added labels to connectors;
    Added mounting holes;
    Changed SMD resistors to size 0805;
    Rearranged components on board
    [mcu-board.kicad_pcb, mcu-board.kicad_sch]
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2024-09-25 Swapped SCL & SDA for consistency
    [mcu-board.kicad_pcb, mcu-board.kicad_sch]
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2024-10-08 Fixed KiCad DRC checks to use reports
    [MAX-M10S SMA Breakout.kicad_pcb, MAX-M10S SMA Breakout.kicad_sch]
2024-10-08 Fixed main.cpp sensor import
    [main.cpp]
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2024-10-18 working gps and no mem leak
    [main.cpp]
2024-10-22 fixed based on tests before october launch
    [SensorBoardNoMCU.kicad_pcb, SensorBoardNoMCU.kicad_sch]
2024-10-22 Final Fixes to Sensor Board
    [SensorBoardNoMCU.kicad_pcb, SensorBoardNoMCU.kicad_sch]
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2024-10-23 Added Matching Circuits
    Will Update in the morning. Values for recommended 50Ω matching network found in pg 14 of here:
    https://www.silabs.com/documents/public/user-guides/EZRadioPRODevKit-UG.pdf
    [low_power_module.kicad_sch]
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2024-10-23 Fixed RF on sensor board
    [SensorBoardNoMCU.kicad_pcb]
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2024-11-04 TCXO and Decoupling Caps Added
    TCXO
    - A 30MHz TCXO was added:
    https://www.digikey.com/en/products/detail/raltron-electronics/RTX-104CHZ1-S-32-000-TR/14558648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
    - 10nF Decoupling capacitors were added to VCC
    - PCB Layout not updated
    [low_power_module.kicad_pcb, low_power_module.kicad_sch]
2024-11-07 fixed rx and tx methods
    [main.cpp]
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2024-11-23 Added Topology and Changed
    Added topology for:
    - Class-E Switched TX/RX Board Configuration (see AN648)
    - 70cm matching network (see AN643)
    - DC blocking capacitors on RF switch IO
    - low pass filter between RF switch and antenna
    I will update / calculate values tomorrow
    [low_power_module.kicad_sch]
2024-11-30 minor schematic fixes and first pass at layout
    Also fixed .gitignore
    [low_power_module.kicad_pcb, low_power_module.kicad_sch]
2024-12-01 add values for filters and matching circuits
    values verified in LTSPICE, also updated .gitignore for KiCAD v8
    [low_power_module.kicad_sch]
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2024-12-02 Edited Trace Width on 50Ω microstrip and Changed Layout with New Filter
    [low_power_module.kicad_pcb, low_power_module.kicad_sch]
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2024-12-05 fix debugging memory error
    [main.cpp]
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2024-12-09 some bug fixes for radio code
    [main.cpp]
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2024-12-14 finishing touches, fix 50Ohm trace width
    Got new width from JLC calculator
    [low_power_module.kicad_pcb, low_power_module.kicad_sch]
2024-12-18 increase clearance between signal lines
    [low_power_module.kicad_pcb]
2024-12-19 working sensor detection and reverse
    [main.cpp]
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2025-01-03 Revert "Merge branch 'RotCam' into pr/DrewBrandt/8"
    This reverts commit 97308bb7714ae8766c95670b973ec1c24a0b5306, reversing
    changes made to 1308c922c2fd8c981e6bde5cf39c0844eb212090.
    [main.cpp]
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2025-01-16 Housekeeping File Updates
    - Removed extra PCB file that somehow got onto the repo
    - Updated PCB file with footprints
    [PCB.kicad_pcb, power-delivery-board.kicad_sch]
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2025-01-17 bluetooth module
    created the PCB for it, and 1 UART for communication. need to check out how to program it using the ESP-PROG board.
    [ESP32_BluetoothModule_TerrapinRockets.kicad_pcb, ESP32_BluetoothModule_TerrapinRockets.kicad_sch]
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2025-01-18 HP module schematic and layout
    who knows if the layout would work
    [high-power-module.kicad_pcb, high-power-module.kicad_sch]
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2025-01-21 Schematic Updates. NOTE: ERC Fails
    [power-delivery-board.kicad_sch]
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2025-01-22 JTAG Connection
    Need this connection to program ESP- Check you tube video I sent to Varun
    [ESP32_BluetoothModule_TerrapinRockets.kicad_pcb, ESP32_BluetoothModule_TerrapinRockets.kicad_sch]
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2025-01-29 fixes based on tests
    [main.cpp]
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2025-02-04 undid live video change (wrong branch for change to occur on)
    [main.cpp]
2025-02-04 undid auto-format of live video revert
    [main.cpp]
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2025-02-26 maybe fix client scanning
    [main.cpp]
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2025-03-05 idk but fixes GPS
    [main.cpp]
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2025-03-06 fix current control cap on ground receiver
    [ground-receiver.kicad_sch]
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2025-03-07 minor additions and fixes to ARCH
    [live-video-multi-function-board.kicad_pcb, live-video-multi-function-board.kicad_sch]
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2025-03-18 reorganize, separate tests into platformio projects, and continue fixing setRegisters
    [RF4463.cpp, RF4463.h]
2025-03-22 Fix RS and add code for I2C operation
    [main.cpp]
2025-03-26 maybe fix serial issue
    [main.cpp]
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2025-04-15 GPS Patch Breakout Updates
    - Updated transmission line to 50 Ohm micro (track width 0.156464 mm)
    - Rounded edgecut corners that conform around mounting holes
    [PatchAntennaBreakout.kicad_pcb, PatchAntennaBreakout.kicad_sch]
2025-04-16 Push
    - Updated trace to 1.77038 mm
    - Updated footprint edge mount SMA footprint - need to check if this is the correct one
    [PatchAntennaBreakout.kicad_pcb]
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2025-04-24 just footprint + library
    haven't done much, will do more after exam
    [high-range-IMU.kicad_pcb, high-range-IMU.kicad_sch]
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2025-05-01 Made pcb
    There is a descirption in the schematic of some stuff i didnt add/was unsure of breaking out
    [high-range-IMU.kicad_pcb, high-range-IMU.kicad_sch]
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2025-05-03 Finished
    Don't know if i did the ground plane correct. Don't know if I did the decoupling capacitor circuit correct.
    [high-range-IMU.kicad_pcb, high-range-IMU.kicad_sch]
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2025-09-02 not working spi
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2025-10-09 high g imu
    pasted in the schematic, make sure to read the text i put in before coding it
    [High-g-IMU.kicad_sc.kicad_sch, IMU.kicad_sc.kicad_sch]
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2025-10-10 Wired_bNO055
    Wired BNO055 sensor based on pinout diagram--mostly if not fully completed now--all pins are wired somewhere.
    [flight_cmptr_1.kicad_sch]
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2025-10-16 Added Adafruit Buzzer
    [drew_example_fc.kicad_pcb, drew_example_fc.kicad_sch]
2025-10-16 autejwani
    Fixed Flight Controller
    [AdityaFlightComputer.kicad_pcb, AdityaFlightComputer.kicad_sch]
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2025-10-16 autejwani
    Fixed Pull up resistors
    [AdityaFlightComputer.kicad_pcb, AdityaFlightComputer.kicad_sch]
2025-10-16 Update IMU and Magnetometer based on feedback
    Added I2C address for gyroscope and accelerometer
    Fixed magnetometer schematic
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2025-10-18 Fixed mistakes Drew Found
    [Barometer.kicad_sch, IMU.kicad_sch, Jack_Yeulenski_Flight_Computer.kicad_sch]
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2025-10-24 leds and buzzer added
    [nick_egorov_flight_computer.kicad_sch]
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2025-10-27 Updated capacitors and Reset/int pin
    [flight_cmptr_1.kicad_sch]
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2025-10-27 Start PCB setup
    Began PCB setup and putting things in a nice place in birdsnest.
    [flight_cmptr_1.kicad_pcb, flight_cmptr_1.kicad_sch]
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2025-10-31 ran DRC; fixed what I could
    [hannah_flight_computer.kicad_pcb]
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2025-11-06 Fixed concerns from Drew
    Hey Jack, just a few things I noticed about your PCB
    First, somehow this resistor got a diode's footprint. Not the biggest issue but its kinda funny (pic 1)
    Generally, it's better to have a continuous ground plane under everything and only run traces on one layer. Idk if it will have any real effect on what we're doing here, so if you don't have time or whatever you can just leave it, but for future projects, it's something to keep in mind. ground planes help with EMI and just generally help things perform better.
    You should connect all of the GND pins on the Teensy to GND (pic 2)
    This is a bit weird but its fine lol (pic 3)
    Finally, you should add some silkscreen wi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
    [Jack_Yeulenski_Flight_Computer.kicad_pcb]
2025-11-06 Amin FC Silkscreen Fix
    [amin_flight_computer.kicad_pcb]
2025-11-06 Amin FC Silkscreen Fix 2 + STEP file
    [amin_flight_computer.kicad_pcb]
2025-11-06 Amin FC Silkscreen Fix 3
    [amin_flight_computer.kicad_pcb]
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2025-11-06 something broke and git does not let me change branches
    [SDCard.kicad_sch]
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2025-11-06 added external I2C, SPI, SWD, UART connectors, cleaned up schematics, and changed STM32 schematic for one with power pins. Need to add decoupling capacitors for STM32, external clock for STM32
    [Barometer.kicad_sc.kicad_sch, ESP32.kicad_sch, GPS.kicad_sc.kicad_sch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]
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2025-11-07 Added LEDS, Buzzer, Oscillator, decoupling capacitors, fixed 3.3 volt netclasses, reorganized main schematic page, added some annotations
    [ESP32.kicad_sch, GPS.kicad_sc.kicad_sch, flight-computer.kicad_sch]
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2025-11-07 Ahlinkar - fixed some errors
    [rockets test.kicad_sch]
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2025-11-08 PCB fixes
    [flight_cmptr_1.kicad_pcb]
2025-11-08 fixed letter placement
    [flight_cmptr_1.kicad_pcb]
2025-11-08 Amin has his 450th mg of caffeine and realizes thicc traces more better
    [amin_flight_computer.kicad_pcb]
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2025-11-08 fixes pcb
    [flight_cmptr_1.kicad_pcb]
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2025-11-09 pcb fixing
    [flight_cmptr_1.kicad_pcb]
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2026-03-06 Replaced BNO with BMI
    [IMU.kicad_sch, Jack_Yeulenski_Flight_Computer.kicad_pcb]
2026-03-06 Fixed some issues
    [Jack_Yeulenski_Flight_Computer-B_Cu.gbr, Jack_Yeulenski_Flight_Computer-B_Mask.gbr, Jack_Yeulenski_Flight_Computer-B_Paste.gbr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]
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2026-03-29 Update Screw Switch PCB and schematic files
    - Increased pad dimensions in Screw Switch PCB from 3.8mm to 9.0mm for improved soldering and stability.
    - Added a new mounting hole symbol in the Screw Switch schematic with properties for reference, value, footprint, datasheet, and description.
    - Created an auto-saved file entry for the STM32 flight computer project to ensure recovery of recent changes.
    [STM32-flight-computer.kicad_sch, Screw Switch.kicad_pcb, Screw Switch.kicad_sch]
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2026-04-01 Backup radio pcb changes 3 (Drew will no longer be shooting me)
    [backup_radio.kicad_pcb]
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2026-04-01 Fix cus stoopid
    [backup_radio.kicad_pcb]
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2026-04-01 Most schematic fixes for ARCH-Mega
    [ARCH-Mega.kicad_sch, charge.kicad_sch]
2026-04-01 fix LDO
    [medium-power-module-telemetry-2.kicad_sch]
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2026-04-24 Remove unnecessary entries related to footprint issues and shorting items from the STM32 flight computer project configuration.
    [STM32-flight-computer.kicad_pcb]
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2026-05-01 mpm add step and fix 3d models
    [MPM.step, medium-power-module-telemetry-2.kicad_pcb]
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2026-06-18 Add radio FHSS hopping; make STM32FC a native ARC node
    Radio module: add command-driven pseudo-random frequency hopping across
    the SRAD band. RADIO START_HOPPING begins a deterministic schedule both
    ends derive from a shared seed; SET_FREQUENCY parks on a fixed channel.
    A hopping link that goes silent falls back to the home channel (now
    909.5 MHz) for re-acquisition; a parked freq does not auto-revert.
    STM32FC: replace the old AvionicsPacketProtocol/Type_2GT path with a
    native ArcNode (ARC_ADDR_FC_N) emitting 10 Hz flight telemetry to the
    hub, plus DataRadioTelem that builds proprietary data-radio frames
    wrapped in RADIO/DATA_DOWNLINK. Remap telemetry UART pins and add
    heartbeat/telemetry d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
    [main.cpp]
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2026-08-22 Fix legacy Teensy radio build configuration
    Use the canonical STM32 environment's shared library list and exclude the standalone ping programs from the normal Teensy firmware build.
2026-08-22 Point legacy avionics builds at canonical libraries
    Replace deleted Astra and Astra-Rocket development branch dependencies with their reconciled main branches, and keep the new STM entry point out of the Teensy target.
2026-08-22 Replace deleted Astra development branch dependencies
    Point the BPP and legacy Spaceport STM32 projects at canonical Astra main. BPP now builds; the older Spaceport prototype still requires an intentional Astra API port.
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2026-09-11 Revert "Merge branch 'main' of https://github.com/Terrapin-Rocket-Team/SRAD-Avionics"
    This reverts commit e5f68e4e525f2a5ad7eebbc917cc2807b67ca5e1, reversing
    changes made to 8a40e2e341d8980ca528983581171a8bd9cc0146.
    [1_PreFlightData.csv, 22_FlightData.csv, 22_PreFlightData.csv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]
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2026-09-27 some small changes to fix organizaiton
    [BMI088.step, BMS.kicad_sch, Barometer.kicad_sc.kicad_sch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]
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
